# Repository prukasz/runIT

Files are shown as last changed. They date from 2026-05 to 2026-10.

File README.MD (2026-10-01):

# runIT

> **`YOU can run IT`**

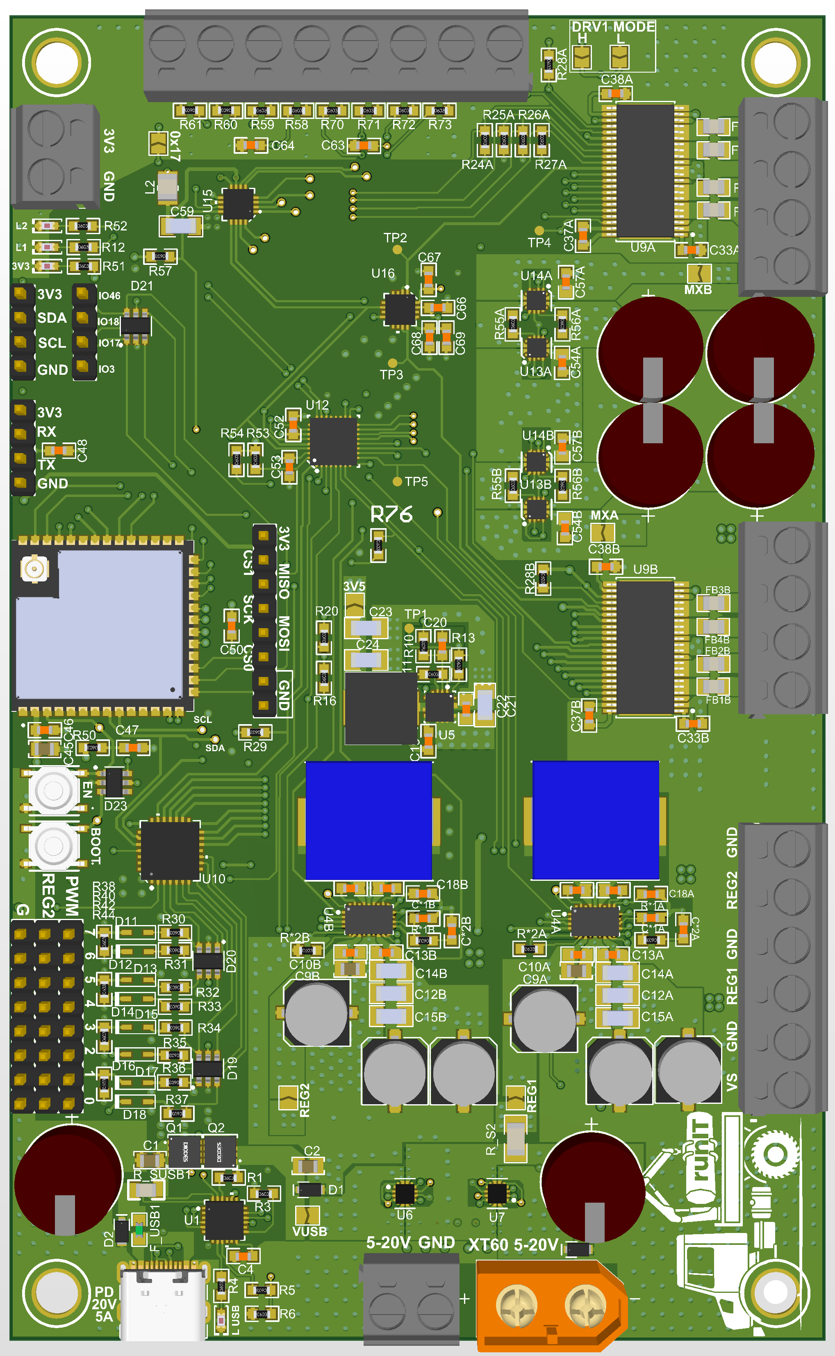
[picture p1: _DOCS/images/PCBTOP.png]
Płytka runIT, widok z góry PCBTOP


---

## Czym jest runIT?

**runIT** to kontroler łączący pogranicze **IoT**, modelarstwa **RC** oraz **automatyki**.

Pozwoli Ci on na podłączenie standardowych elementów RC (takich jak serwa, ESC, różnego rodzaju aktuatory) oraz łatwą integrację popularnych czujników i pasków LED. Dzięki aplikacji stworzysz interfejs sterowania, a za pomocą prostego języka graficznego uczynisz swój projekt "SMART" i podłączysz go do sieci.

## Co oferuje sterownik runIT

- PowerIO 20V
- Dwie regulowane przetwornice DC-DC
- Elastyczne zasilanie, w tym USB-C PD
- PWM expander
- WiFi + BLE
- Zabezpieczenia

Całość na popularnym mikrokontrolerze ESP32-S3.

### PowerIO

- 4 konfigurowalne mostki H (8 wyjść) - nawet 20V 5A
- 8 wejść analogowo-cyfrowych gotowych do bezpośredniej pracy z napięciem do 20V
- System wyboru źródeł zasilania dla mostków H - zasil elementy wymagające różnych napięć bezpośrednio z płytki
- Zasilanie mostków H z przetwornic DC-DC lub bezpośrednio z zasilacza
- Pomiar poboru prądu i tryb Constant Current

### Regulowane przetwornice DC-DC

- Swobodna regulacja w zakresie 4.5V - 20V
- Zabezpieczenia przeciwzwarciowe i przeciążeniowe
- Limit poboru prądu
- Wyjścia bezpośrednio z przetwornicy - zasilacz regulowany

### USB-C PD i wejście uniwersalne zasilania

- Wsparcie USB-C PD 3.0 20V-5A
- Wejście na akumulator lub zasilacz 5V - 20V wraz z pomiarem poboru prądu i napięcia
- Możliwość koegzystencji obu wejść zasilania

### PWM expander

- 8 kanałów dedykowanych wraz z wyjściami 3-pinowymi
- Współpraca z Servo i ESC bez zajmowania innych kanałów

### WiFi + BLE

- Połączenie WiFi i BLE lub oba na raz

### Zabezpieczenia

- E-bezpieczniki
- Zabezpieczenie przeciwko odwrotnej polaryzacji
- Zabezpieczenia ESD
- Izolowane zasilanie 3.3V
- Regulowany limit prądu zasilania
- Pomiar napięcia i poboru prądu - alerty

### ESP32-S3

- Wyprowadzone GPIO, w tym SPI i I2C
- Brak ograniczenia jedynie do wbudowanych peryferiów - podłącz popularne czujniki
- Ekosystem ESP-IDF - łatwa modyfikacja do swoich potrzeb

## Co oferuje oprogramowanie

- Prosty język blokowy z wbudowanym wsparciem "RC"
- Tryb smart - pilot RC
- Wsparcie dla popularnych elementów modelarskich
- Prosta konfiguracja podpiętych elementów oraz WiFi i BLE
- Ułatwione wykrywanie błędów
- Łatwy dostęp do danych telemetrycznych
- Zabezpieczenia działające w tle

### Język blokowy

- Drag 'n drop
- Automatyzacja prostych rozwiązań
- Wyślij zebrane dane przez BLE lub WiFi
- Dedykowane bloki sterujące dla elementów modelarskich
- Podgląd zmiennych na żywo
- Edycja kodu na żywo i OTA
- Ułatwiona konfiguracja podpiętych elementów i wybranego zasilania - ustaw napięcie, a resztą zajmie się oprogramowanie

### Tryb RC

- Połącz kod z pilotem na urządzeniu
- Wykonuj skomplikowane sekwencje niemożliwe w zwykłej aparaturze RC

### Potrzebujesz bardziej skomplikowanego oprogramowania?

- Zaimplementuj je równolegle w C i utwórz nowy blok
- Uruchom go równolegle z kodem blokowym
- Wykorzystaj sprzęt oraz sterowniki i napisz własny kod

---

## Stan projektu

**Płytka jest już wyprodukowana i uruchamiana.** Firmware i aplikacja powstają równolegle.

### Działa (sprawdzone na płytce)

- Uniwersalny system wymiany danych z aplikacją - przez BLE i UART
- Sterowniki: GPIO ESP, ekspander TCA6424A, ADC ADS7128, PWM PCA9685, USB-C PD AP33772S i kolejne układy zasilania
- Komendy, odpowiedzi, błędy i logi dekodowane w aplikacji
- Zdarzenia na urządzeniach i akcje uruchamiane zdarzeniami
- Maszyna wirtualna (VM) z 15 typami bloków, m.in. wyrażenia, warunki, pętle, timery, zatrzask, detektor zbocza, wyjścia IO
- Zapis programu w pamięci płytki i jego wczytanie po restarcie
- Aplikacja (przeglądarka, Web Bluetooth): widok płytki i urządzeń, edytor bloków z płótnem (canvas), kompilator programu, tryb debugowania z podglądem zmiennych na żywo

### W trakcie

- Wysyłanie programu z edytora blokowego na płytkę w pełnym przepływie z poziomu aplikacji
- Wybór źródła zasilania mostków H (z blokadą przed zwarciem źródeł)
- Zasilanie: potwierdzenie kolejności kanałów INA3221, wskaźniki źródła, estymaty
- Testy VM na sprzęcie dla bloków Latch, Periodic, Action i On Event

### Planowane

- Tryb RC - pilot w aplikacji połączony z kodem blokowym
- Telemetria i rejestrator danych
- Strona zasilania i subskrypcji zdarzeń w aplikacji
- WiFi (w tym MQTT) jako kolejny kanał danych
- Aplikacja mobilna (Android)

## Struktura repozytorium

| Folder | Zawartość |
|---|---|
| `_SOFTWARE` | Firmware ESP32-S3 (ESP-IDF), deskryptory danych i aplikacja webowa |
| `_HARDWARE` | Projekt płytki: schematy i PCB (Altium) |
| `_DOCS` | Obrazy i dokumentacja do README |

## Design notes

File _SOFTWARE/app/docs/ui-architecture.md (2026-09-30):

# UI architecture

## Screen frame

`src/App.tsx` coordinates the active view and workspaces. It supplies content to `src/layout/WorkspaceLayout.tsx`, which owns the stable three-column structure:

| Region | Purpose | Typical content |
| --- | --- | --- |
| Explorer | Tree, palette, and lists | Variables, blocks, devices, settings categories |
| Main screen | Canvas or editor | Block canvas, object editor, device editor, settings editor |
| Details | Selection details and actions | Block settings, object information, device commands, run and connection panels |

The main screen receives a toolbar slot from `App.tsx`, so actions can change with the active view without changing the frame. The terminal is below the main screen.

The explorer and details panels share `side-panel`, `side-panel-header`, and `side-panel-collapsed-icons` styles. The three panel resize handles share `panel-resize-handle`; their direction and placement stay in the feature classes.

## Shared controls

| Component | Use |
| --- | --- |
| `components/FormField/TextField` | Native text and number inputs with shared border, focus, disabled, and invalid states. Checkbox, file, and other native controls retain their native appearance. |
| `components/FormField/SelectField` | Native dropdowns with the same field surface and focus behavior. Keep native select semantics for finite choices. |
| `components/EditableField` | A text field with an edit or protected icon. Supports editable, read-only, and disabled values. |
| `components/ListableField` | A dropdown with option data and a chevron or locked icon; built on `SelectField`. |
| `components/PaletteSearch` | Search input, icon, clear action, and Escape behavior for explorer palettes. Views supply their own filtering rules. |
| `components/PaletteSectionHeader` | Collapsible palette heading with chevron, label, filtered count, and optional Add action. Views own expanded state and filtering. |
| `components/InlineRename` | One commit or cancel path for canvas names, block names, and aliases; callers decide how to validate the final text. |
| `components/Badge` | Passive chip for system markers, IDs, counts, BLE flags and directions, detail labels, and type codes. Set a semantic `tone`; use `size="compact"` for dense flags, `size="detail"` in inspectors, `caps` for uppercase status text, and `push` for edge alignment. `filled` is used for prominent accent labels. |
| `components/Button` | `Button` (`variant`: default, primary, danger, dashed; `size`: md 32px, sm 28px, icon, icon-sm; `block` fills the row), `buttonClass()` for a link styled as a button, and `ToggleChip` (pill with `selected`). Features add no button colors, borders, or icon sizes of their own; toolbar and tree icon buttons keep the shell's plain `.shell button` style. |
| `components/Card` | `Card` (title, optional amber `icon`, `subhead`) is the panel surface for a group of settings; `CardStack` stacks the cards of one editor page. |
| `components/FormField/FormRow` | `FormRow` (label above one control, optional `htmlFor` / `note` through `FieldLabel`, `hint` under the control) and `FormGrid` (two columns, one when narrow). |
| `components/PanelHeader` | Title row at the top of a details panel: leading `icon`, `title`, then badges or actions as children. |
| `components/TypeBadge` | Exact VM or BLE type codes and the broader value-kind icon used on objects and block pins. |
| `components/OptionMenu` | Rich option lists with a shared option row, selection state, arrow navigation, and Escape. Canvas wiring and accessor suggestions use it. |
| `components/TreeSlab` | Shared leading badge, label, trailing badges, and optional action row for variables, devices, connectors, and the block palette. |

`TreeSlab.css` owns row selection, folder, search match, link target, drag, and drop states. A feature should add only its own row content or spacing rules.
Use `Badge` for static labels. Buttons and selectable chips keep their own interaction styles and semantics.
Flat palettes can give the row a `listitem` role and disable activation when their item is unavailable. The row's main button supplies Enter and Space activation; drag handlers remain on the row container.

Use a native select for ordinary finite choices. Use `OptionMenu` when a row needs badges, descriptive text, live filtering, or a drop target. Keep the options and their domain rules in the feature; the shared component owns the common interaction and surface.

Use `form-field-panel` on `TextField` or `SelectField` for fields on a panel surface. A compact field can set `--field-height`, `--field-padding`, and `--field-font-size` on its container. The shared control keeps the border, focus, and disabled states.

`EditableField` and `ListableField` share the `adorned-field-wrap` and `field-adornment-*` styles from `FormField.css`. Their own stylesheets contain only control-specific sizing. Native fields supplied through `TextField` and `SelectField` should keep their common border, colors, and focus state in `FormField.css`; feature CSS should only override the needed dimensions or layout.

## Feature boundaries

`src/domain/` contains project data, catalogs, wiring, compilation, and other rules independent of React. `src/devices/` and the workspace modules contain their feature views and state hooks.

The canvas feature is grouped by responsibility:

| Directory | Contents |
| --- | --- |
| `canvas/blocks/` | Block rendering, details, formula editing, pin helpers, and block-specific rules. Accessor parsing lives in `pinAccessors.ts`; `PinHelpers.tsx` uses it. |
| `canvas/surface/` | Pan and zoom interaction, wires, free chips, and branch or loop regions. |
| `canvas/workspace/` | Canvas editor composition, tabs, block palette, and workspace state. |
| `canvas/index.ts` | Public imports for the rest of the app. |

`canvas/Canvas.css` remains the feature stylesheet and is imported by the feature views.

## File view

`ProjectFile.tsx` is the File view (first icon in the left rail): the left panel holds New, Open, Save (project file), Import and Export (code file, `runit-code`) and Recover from board; the main screen shows what the project holds and the code it builds. The Run view keeps only what changes a board: Store, Load, Erase. `useProjectCode` builds the code once for both.

## Names shown to users

Block enable pins keep their PLC names in code, data files and paths (`EN`, `ENO`, `enables`, `<id>:eno`), but the screen says what they do: **EN** is **Run when** (the block runs only while it is true), **ENO** is **When done** (true after the block ran), and a FOR's ENO is **Loop body**. Use these in labels, titles, hints and messages.

## Color palette

`src/styles/theme.css` is the source of dark and light theme colors. The shell owns surface tokens such as `--background`, `--panel`, `--divider`, `--active`, `--muted`, and the blue selection token `--accent`. Use `--color-*` for status and accent hues, `--type-*` for badges, `--category-*` for block categories, `--group-tint-*` for canvas contours, and `--syntax-*` for expression text. Mix a token with `transparent` for translucent backgrounds and glows so both themes use the same hue. Keep literal colors only for fixed contrast marks or artwork.

`src/hooks/useStorage.ts` owns browser storage: `readStored` / `usePersistEffect` for workspace data, `usePersistedChoice` / `usePersistedFlag` for remembered preferences (tab, mode, theme, snap). Every read and write is guarded, so a view never repeats the try/catch. `src/hooks/useUndoHistory.ts` owns the common undo transitions and 50-entry limit. Object edits can group rapid changes with a key; project loads in canvas, devices, and objects are undoable, while loading a BLE profile starts a fresh history. Each workspace keeps its own storage, validation, and selection behavior.

When adding a screen, provide its explorer, main content, details, and toolbar actions through `App.tsx`. Reuse the shared controls before adding feature-specific field or dropdown styling. Feature CSS should describe layout and meaning, such as the importance level color; control focus and disabled behavior belong to the shared component.

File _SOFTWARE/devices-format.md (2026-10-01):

PORTS:

POWER:
SUPPLY_OUT {MIN mV/mA,MAX mV /mA, REGULATED, POWER_MAX}
SUPPLY_IN {MIN,MAX}
GND {}
MEASURE_IN{MIN, MAX}
MEASURE_OUT

IO: + overall types (pullup and so on)
BINARY
PWM 
ADC
DAC
PROTOCOL(i2c){MEMEBER(SCL)} 

do tego defaul modes itd

descripotion of PORT:
PORT + name + svg id + real-device-id if possible to configure

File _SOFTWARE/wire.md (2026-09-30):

First read concept if unsure ask. 
I dont know how to make EN and ENO seamless for user - so he uses if only wants
help me with thise one settled we move to implementation 

First global variable accessor:
- let it be a short rectangle with name of accessed
- if to long - truncated to last important path like ...temperature 
- when clicked then automatically right screen pops out to edit if requires manual. 
- if drag n drop is enough - it should be enough to drag from folders and varaibles and put on block 
- when hovered over block during wiring - there appears zoom over block with pin to chose or EN 
- IN can be selectable both by dropping object on enlarged pin or by clicking on pin in enlarged view

- when enlarged view displays few pins - only compatible type is allowed (number and bool are casted - so allowed ) but ptr and string is not capable 

- you can drop empty accessor from top toolbar - that way every pin is allowed to drop on but still end result must be compatible

- if possible accessor should then snap to block - so no wire but still if required can be moved out with an wire

Then ENO and EN:

- ENO is Green stripe 
- EN is Red stripe

- When output of block is connected to input of any - then ENO is automatically - linked 

Then canvas marking:

- Every block in for loop should be included as grouped in smoke like area - contour - those then can overlap with eachother. each of group are shold posess slight coloru tint
- same thing for IF block and SWITCH. this will visually help understand code

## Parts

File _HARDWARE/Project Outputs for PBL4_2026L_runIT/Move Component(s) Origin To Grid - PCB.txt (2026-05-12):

Move Component Origin to Grid
Filename     : C:\Users\krolp\Documents\runIT\_HARDWARE\PCB.PcbDoc
Date         : 02.04.2026
Time         : 00:08:12
Time Elapsed : 00:00:00

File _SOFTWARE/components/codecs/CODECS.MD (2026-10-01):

# CODECS — Packet Decoder Tables

`codecs` is a **header-only** component holding the packet tables that [[SYS_INTERFACE.MD]] routes to. It has no source files and produces no library — `idf_component_register()` only exports `decoders/` (inbound packet tables, one header per class byte).

Every class is registered with `sys_interface` by runit's `runit_register_decoders` boot step (`components/runit/runit.c`), before `sys_interface_init()` starts the RX receiver. `sys_interface` itself doesn't depend on `codecs`.

The error-chain encoder that used to live in `encoders/` is private to `sys_errors` now (`components/sys_errors/enc_sys_errors.h`); its wire format is in [[SYS_ERRORS.MD]] "Logging and telemetry".

The split of responsibility: `sys_interface` owns the **class byte** (`0xXX`) and the transport plumbing; a codec header owns its **packet bytes** (`0xYY`), payload layouts, and the mapping to `sys_*` API calls.

---

## `decoders/dec_sys_contracts.h` — class `0x01`

Maps packet bytes onto the system contract APIs (`sys_device`, `sys_io`, `sys_power`). Everything is `static inline` in one header, so adding a packet is a single-file change with no build-system edits.

Each entry is three pieces:

```c
#define HEADER_packet_sys_io_toggle_t 0x24          // 1. packet byte
typedef struct __packed {                            // 2. payload layout
  uint8_t device_id;
  uint8_t pin;
} packet_sys_io_toggle_t;

static inline err_h decoder_packet_sys_io_toggle_t(packet_sys_io_toggle_t* packet) {
  ESP_LOGI(DEC_SYS_CONTRACTS_TAG, "toggling io (dev %u, pin %u)", packet->device_id, packet->pin);
  return sys_io_toggle(SYS_IO_REF(packet->device_id, packet->pin));
}
```

...plus a row in the central `X`-macro list:

```c
#define SYS_CONTRACTS_PACKET_LIST(X) \
  ...                                 \
  X(HEADER_packet_sys_io_toggle_t, packet_sys_io_toggle_t, decoder_packet_sys_io_toggle_t)
```

`SYS_CONTRACTS_PACKET_LIST` expands through `SYS_CONTRACTS_DECODE_CASE` into the `switch` inside `dec_sys_contracts_decode()`, which runit registers for class `0x01`. Each case declares the payload struct on the stack, fills it via `convert_to_packet()` (length-checked), and calls the decoder.

Every decoder logs what it is about to do at `ESP_LOGI` under the tag `dec_sys_contracts`. A getter returns its result in the command's response: it declares `packet_<name>_response_t` (packed, scalars or fixed scalar arrays, same field annotations) next to its request struct and calls `sys_interface_respond(&rsp, sizeof(rsp))`. Every command is answered (`[0x05][seq][class][packet][status][data]`, see [[SYS_INTERFACE.MD]] "Responses"). The contracts generator publishes the response layout.

### Packet Byte Ranges

| Range | Domain | API |
| :--- | :--- | :--- |
| `0x10`–`0x15`, `0x1A`–`0x1C` | Device lifecycle | `sys_device_user_uninstall` (onboard devices are refused), `reset/suspend/resume` (+ `_all` variants; `0x1C` → `sys_device_user_uninstall_all`, which skips onboard devices) |
| `0x1A` | Device error handling | `sys_device_set_error_handling` — `device_id, importance, actions[5]`; see [[SYS_DEVICE.MD]]'s "Per-Instance Error Handling" |
| `0x1B`–`0x1F` | *(free)* | |
| `0x20`–`0x2F` | IO | `sys_io_reset/set_mode/set_level/get_level/toggle/get_voltage/set_voltage/set_pwm_frequency/set_pwm_duty`, `0x29`: `sys_io_configure_intr` (mode, debounce, ADC window; arms the pin only, events are linked with class `0x09`) |
| `0x31`–`0x3E` | Power | `sys_power_vreg_set_enable/voltage/current` (budgeted, current 0 = automatic), `sys_power_monitor_get_voltage/current`, `sys_power_usb_pd_set/list/get_limits`, `0x39`: `sys_power_monitor_set_alert` (current alert threshold), `0x3C`: `sys_power_get_status` (response), `0x3D`: `sys_power_set_response`. `0x30`, `0x3A`, `0x3B` and `0x3E` are free. Persisted PSU / battery settings are settings class `0x08` (`dec_settings_power.h`). |
| `0x51`–`0x53` | H-bridge | `sys_hbridge_set_drive/brake/coast`. `0x50`, `0x54`–`0x56` are free: set_mode, set_current_limit and clear_fault were chip specifics and are operations of the DRV8962 now (`0x80`–`0x82`, [[SYS_DEVICE.MD]] Packet Router). Faults are events, class `0x09`. |
| `0x00`, `0x80`–`0xFF` | Device router | create a device by type id; operations of a device ([[SYS_DEVICE.MD]], Packet Router) |

Unmapped packet bytes raise `ERR_INTERFACE_UNKNOWN_PACKET` (owner `OWNER_DEC_SYS_CONTRACTS`) and log a warning.

---

## Device creation — class `0x01`, header `0x00`

Devices have no install packets (the old `0x40`–`0x47` decoders are gone). A device is created by the packet router: `[0x00][type_id][d_<chip>_cfg_t]`, where the cfg is the device's own `__packed` wire struct, device_id first. `sys_device_route()` finds the class by `type_id` and `sys_device_create()` checks the size and the pin order ([[SYS_DEVICE.MD]], Packet Router). The cfg struct and its annotations live in the device's own header (`components/devices/device_<chip>/include/device_<chip>.h`), which the device generator reads.

A pin on another device is a `sys_io_pin_ref_t` (`device_id, pin, mode`, three bytes). **An unused pin must be encoded as `pin == SYS_GPIO_NONE`** (`0xFF`); sending all-zero fields means "device 0, pin 0", a real pin. `i2c_bus` is a single byte (`0` = internal, any other value = external bus). Example: a PCA9685 as device 5 on the internal bus at I2C address `0x40`, no OE pin: `01 00 41 05 00 40 00 FF 00`.

---

## `decoders/dec_sys_actions.h` — class `0x03`

Control-packet table for [[SYS_ACTIONS.MD]]'s record/stop/remove wire protocol. Same shape as `dec_sys_contracts.h` (a `SYS_ACTIONS_PACKET_LIST` X-macro expanded into a switch), just with `sys_actions.h` in place of `sys_io.h`/`sys_device.h`/`sys_power.h` as the thing being wrapped.

| Packet | Byte | Payload | Calls |
| :--- | :--- | :--- | :--- |
| Static Invoke | `0x00` | `uint8_t id` | `sys_actions_invoke(SYS_ACTION_SCOPE_STATIC, id)` |
| Dynamic Invoke | `0x01` | `uint8_t id` | `sys_actions_invoke(SYS_ACTION_SCOPE_DYNAMIC, id)` |
| Record Start | `0x02` | `uint8_t id` | `sys_action_record_start(id)` |
| Record Stop | `0x03` | *(empty)* | `sys_action_record_stop()` (persists to NVS) |
| Remove | `0x04` | `uint8_t id` | `sys_action_remove(id)` |
| Remove All | `0x05` | *(empty)* | `sys_action_remove_all()` |

`CONFIG_RX_PACKET_CLASS_SYS_ACTIONS` (`0x03`) and every other class/packet wire-identity byte are Kconfig options under `components/utils/Kconfig`'s "System-Wide Identity Assignments" menu, not `#define`s in any one file — see that menu's "RX/TX Packet Classes" and "RX/TX Packet Headers" submenus for the full byte-0/byte-1 naming scheme. `dec_sys_actions.h` includes `sys_actions.h` for the rest of that component's own API, not for this constant.

Registered by runit like every other class. There is no separate "bind action to state" class anymore — the `sys_states` component that used to own it was folded into `sys_actions` (a hardcoded behavior is now just a bound static function on an action id, see [[SYS_ACTIONS.MD]]); class `0x04` was freed by that change and has since been taken by the VM loader below.

---

## `decoders/dec_vm_loader.h` — class `0x04`

Records are the packed structs of `VM/core/loader/vm_wire.h`, published to `data-structures/vm/vm-program.generated.json`.

Program-upload table for [[VM.MD]]. **Structurally different from the tables above**: these packets are not fixed-size structs, so there is no `X`-macro packet list and no `convert_to_packet()` copy. `0x42`/`0x43` carry a repeating record list whose entries vary in length (inline name bytes, inline payload bytes), so they are walked with an explicit cursor.

| Packet | Byte | Payload | Calls |
| :--- | :--- | :--- | :--- |
| Reset | `0x40` | — | `vm_loader_reset()` |
| Open | `0x41` | `u16 obj_cnt`, `u16 acc_cnt`, `u16 blk_cnt`, `u32 total_size` | `vm_loader_open()` |
| Add objects | `0x42` | `u8 n`, `n ×` `{u16 id, vm_obj_head_t head, char name[head.d.name_size]}` | `vm_loader_add_obj()` per record |
| Set data | `0x43` | `u8 n`, `n ×` `{u16 id, u16 start_idx, u16 byte_len, u8 data[byte_len]}` | `vm_loader_set_data()` per record |
| Add accessors | `0x44` | `u8 n`, `n ×` `{u16 acc_id, u16 root_obj_id, u8 idx_count, u8 idx_len, u8 idx_data[idx_len]}` | `vm_loader_add_accessor()` per record |
| Add block | `0x45` | one block: header, `in_cnt ×` accessor id, `q_cnt ×` object id, `en_cnt ×` accessor id, `custom_len ×` private state | `vm_loader_add_block()` |

`idx_data` holds `idx_count` records of `{u8 kind, payload}` — `LITERAL` a `u32` position, `REF` a `u16` accessor id, `NAME` a `u8` length then that many unterminated bytes. A `REF` target must already exist, which makes reference cycles unconstructable rather than merely depth-capped at resolve time.

`0x45` carries exactly **one** block, unlike everything else here: a block record varies in length four separate ways, so batching would need a length prefix per record and a cursor that can desynchronise. A block names accessors and objects that must already be bound. **Block order is execution order** — the client topologically sorts and uploads in that order.

All multi-byte fields little-endian. Every length is checked against the bytes actually present before use (`DEC_VM_NEED`), raising `ERR_VM_LOAD_SHORT_RECORD` rather than reading past the frame — the cursor walk has no struct-size check to lean on, so this is the only thing standing between a truncated frame and an overread.

`DEC_VM_NEED`'s parameters are named `in_pkt`/`in_off`/`in_len`/`in_need` so plain token substitution cannot collide with the `.packet`/`.need`/`.got` payload designators inside it — the same hazard `SE_CHECK_IN_RANGE` documents in [[SYS_ERRORS.MD]]. Naming them `packet`/`need` expands `.packet = (packet)` into `.0x41 = (0x41)`.

Wire-format rationale (`start_idx` unconditional, `payload_size` in bytes rather than an element count, explicit flags byte rather than the raw header bitfield, child **ids** rather than pointers for `VM_OBJ_PTR`) is documented in [[VM.MD]].

Registered by runit like every other class. The VM can't register it itself: `codecs` `REQUIRES VM` so the decoder can see `vm_loader.h`, which would make a `VM → codecs` dependency circular.

---

## `decoders/dec_settings_project.h` — class `0x0A`

Stored code ([[SYS_PROJECT.MD]]): begin / write / commit / abort / erase / options / info / read / load. Settings-style table (`//@settings project`, published to `settings.generated.json`, the `info` response layout too). `write` carries a trailing `uint8_t data[]` (the settings generator publishes it as `flexible_array` without an encoding: opaque bytes); `read` answers with the raw bytes. The header also holds the commit filter (`dec_settings_project_frame_allowed`: no class `0x0A`, no action recording, no VM exec) and `dec_settings_project_is_vm_frame` for the boot replay, which runit wires in `runit_project_boot`.

---

## `decoders/dec_sys_events.h` — class `0x09`

Links events to the program and to actions ([[SYS_EVENT.MD]]). Exposed as the `events` contract catalog.

| Packet | Payload | Response |
|---|---|---|
| `0x01` subscribe | `domain, device_id, channel, event` (255 = any), `route_mask` (bit 0 = program), `static_action_id`, `dynamic_action_id` | `subscription_id` |
| `0x02` unsubscribe | `subscription_id` (255 = every subscription made by packets) | — |

Packet subscriptions are user-owned: the unsubscribe packet can't remove the system's own (device IRQ chaining, power manager). Tagged `OWNER_DEC_SYS_EVENTS` (`0xA618`).

---

## Adding a New Class

Copy the shape of `dec_sys_contracts.h`:

1. Create `decoders/dec_<name>.h` and add a `config RX_PACKET_CLASS_<NAME>` (`hex`, `default 0xXX`) to `components/utils/Kconfig`'s "RX Packet Classes" submenu, under "System-Wide Identity Assignments" — do not `#define` the class byte in the decoder file itself.
2. Set `#undef OWNER` / `#define OWNER OWNER_<NAME>` near the top so `SE_*` macros tag errors correctly, and add that owner to the module's `sys_error_*.h` owner map.
3. Expose one `static inline err_h dec_<name>_decode(const uint8_t* data, size_t len)` — `data[0]` is the packet byte.
4. Register it in `runit_register_decoders()` (`components/runit/runit.c`): `sys_interface_register_decoder(CONFIG_RX_PACKET_CLASS_<NAME>, dec_<name>_decode, "<name>")`.

Per-packet header bytes (byte-1, `data[0]` inside the decoder) stay local `#define HEADER_packet_<struct>_t 0xYY` in the decoder file, as today — only the outer class byte (byte-0) moved to Kconfig, since it's the one value that must stay globally unique across every registered decoder.

Note that a decoder header defines `OWNER` for the rest of the translation unit; any `.c` including it must re-`#define OWNER` afterwards. This is why the registrations live in their own file, `runit.c`.

**Splitting a class across files.** If one class's packet table grows too large for one header, split it into a second header: give the split-out file its own `OWNER`/log tag and its own `SOME_NAME_PACKET_LIST(X)`, then have the original file `#include` it and fold that list into its own via `SOME_NAME_PACKET_LIST(X)` as one line inside its own `X`-macro definition (same technique `sys_error_codes.h` uses to combine multiple modules' `SYS_ERROR_*_MAP(X)`s into one `SYS_ERROR_MAP(X)`). The class byte, dispatcher function, and registration call stay in the original file — only packet declarations move.

### VM execution control

`04 48 <command>` is the single execution-control packet; the command is one
byte and no additional payload is accepted. Commands `00` through `08` select
scan mode, execute once, select block mode, execute next, reset to scan start,
select normal mode, pause, resume, and reset/unload respectively. See
`components/VM/VM.MD` for stepping and reset semantics and
`vm_exec_command_e` for the C constants.

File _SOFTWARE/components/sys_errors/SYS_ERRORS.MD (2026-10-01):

# System errors

Update this document when changing the error core, dispatcher, or tag maps.

## Pipeline and ownership

Errors are typed nodes linked through `next_cause`. `NULL` means success.
`SE_ERR_NEW` creates an owned node; `SE_WRAP_ERR` transfers ownership of its cause
into the new chain. Explicit-owner variants use the same allocator/constructors.
Do not share a cause between two owned chains.

```text
create -> wrap while returning -> SE_REPORT / SE_push_to_handler
       -> validate -> outermost node through causes -> diagnostics -> release
```

`SE_push_to_handler` **consumes** its argument, including when reporting is
suspended. Do not inspect, return, or release that handle afterwards.

- **Responses run synchronously** in the reporting task (device policy, domain hooks,
  system fault), so a response happens before anything else can build on the
  unhandled error.
- **Logging and telemetry run later** in the error log task: `SE_log(chain)` queues
  the chain (consumes it), and that task logs, encodes, sends and releases it. The
  ~1.5 KB of format/encode buffers live on that task's stack, not on the stack of
  every task that raises errors.
- **Queue full:** a chain that finds the queue full (`CONFIG_SYS_ERRORS_LOG_QUEUE_LEN`,
  default 4) is released and counted, and the count is logged.
- **Waiting chains keep their pool nodes,** so keep the queue short.

`SE_send`, the encoder, logging functions, and policy hooks **borrow** their input.
They do not retain it. Their non-NULL return is a separate owned failure.
Use `SE_release(error)` after inspecting/discarding an error yourself.
`SE_IS_OK` / `SE_IS_ERR` only compare; they do not release an error.

```c
err_h error = operation();
if (error) {
  SE_log(error);             // diagnostics only (queued, consumed); or return error to the caller
}
// At an origin with no further use of the error:
SE_REPORT(operation());
```

## Storage and validation

The shared pool is 1,024 bytes: 32 blocks of 32 bytes, reserved with a 32-bit atomic
bitmap. A node occupies consecutive blocks. A 32-byte start-length table validates
node boundaries and complete tag-sized payloads. Tracking costs 36 bytes. There is
no heap allocation and live nodes are never overwritten. Payloads and nodes remain
8-byte aligned. Maximum concurrent capacity depends on payload sizes (up to 32
small nodes); synchronous handling does not eliminate overlapping producer tasks.

`SE_alloc_bytes` validates tag and exact payload size and returns NULL on exhaustion.
Prefer the constructors: a failed new error returns an immutable
`ERR_BASE_POOL_EXHAUSTED` node. It is LOW severity on purpose: a burst of errors
must not trigger the safe state. Pool size: `SYS_ERRORS_BUF_SIZE / SYS_ERRORS_BLOCK_SIZE`
must be at most 32 blocks (one `uint32_t` bitmap, checked at compile time); a failed wrap preserves its existing cause, omitting the new context. Never
mutate the exhaustion node. Long-lived errors consume pool capacity until released.
The pool can exhaust without corrupting another chain; it does not guarantee that
all context can be retained during an error storm.

`SE_collect_chain` returns at most `SE_MAX_CHAIN_DEPTH` (16) unique validated nodes,
outermost first, plus a completeness flag. Handler, logger, encoder and root lookup
share this traversal. Cycles, invalid pointers and longer chains terminate safely.
Malformed/incomplete chains are diagnostic-only. `SE_release` frees the complete
pool-backed chain (also beyond the traversal limit) with bounded cycle detection.
Raw pointers are not generation handles: using a handle after consumption/release
remains invalid, even if its address is later allocated again.

## Dispatch policy

- Device attribution uses the tag payload, independently of the reporting owner.
  Device tags, IO pin tags and power-budget tags identify device instances; each module
  lists its own in `SYS_ERROR_<MODULE>_DEVICE_TAGS(X)` next to its tag definitions, and
  `SYS_ERROR_DEVICE_TAGS(X)` (`sys_error_codes.h`) gathers them for the handler. A listed
  tag without a `dev_id` member does not compile.
  Contract boundaries wrap failures with the affected device ID.
- Visit outermost node to root cause. For a repeated device, use the highest local
  severity among its mentions before the first ignored-device boundary. Run that
  device's policy once, at its first occurrence; pass the node supplying that level.
  The leaf does not silently replace another node's severity.
- A dependency wrapper (`ERR_DEV_DEP_FAILED`, `ERR_DEP_FAILED`) has no severity of its
  own for a device: it takes the severity of the first node below it that is not a
  wrapper. The dispatchers wrap every failure of a device call in `ERR_DEV_DEP_FAILED`
  (HIGH), so without this rule a rejected argument (`ERR_INVALID_VAL_*`, LOW) would
  count as a HIGH fault and run the device's action. A chain made only of wrappers
  keeps the node's own severity. Non-device nodes (domain hooks, the system hook)
  are classified by their own tag as before.
- Importance NONE stops all handling of that device and all deeper causes,
  critical nodes included (the user's opt-out for a device under test). Earlier
  responses remain in effect; the full chain still goes to diagnostics.
- From LOW (a device's start value) up, importance filters which noncritical
  severities reach the device policy: MEDIUM admits HIGH, HIGH admits MEDIUM and
  HIGH, CRITICAL admits all. Critical always goes through. Tag severities stay
  unchanged.
- Domain hooks receive `(node, full_chain)` for each visited node in that domain.
  Hooks are registered at boot (`SE_register_domain_hook(domain, fn)`, a table of
  `CONFIG_SYS_ERRORS_MAX_DOMAIN_HOOKS`); a domain without one is skipped. The device
  router (`SE_register_device_router`) and the system hook (`SE_register_system_hook`)
  are registered the same way. runit does all of it in `runit_error_wiring_init()`,
  the first boot step after `SE_init()`.
- Unattributed critical errors (where no device in the chain was attributed,
  `handled == 0`) use the registered system hook, never a lookup of device zero.
  The application latches the triggering node and performs global stop/suspend
  once per latch episode. Enabled devices still run their individual actions
  after the global latch has been set. The dispatcher deduplicates devices
  per incident, not across separate incidents.
- Response failures are diagnostics-only and released after sending. A per-task
  handler guard prevents callbacks/actions re-entering policy while handling an
  incident. Hooks must return new owned failures, never the borrowed input chain.

`SE_suspend` / `SE_resume` are nested and task-local. Suppression in one task does
not drop unrelated errors from another task. The synchronous dispatch/logging API
is for task context; it can invoke actions, transport callbacks and VM barriers.

## Logging and telemetry

`SE_set_logging(level, mirror_serial, trace_errors)` controls text logging and the
ESP log interceptor. `sys_errors` knows no transport: output goes to a sink the
application binds at boot with `SE_register_sink(&(sys_error_sink_t){send_log,
send_packet, packet_max_len})`. runit (`runit_board_error_sink_init`) sends text
lines to the logs connector and binary error packets to the errors connector.
`packet_max_len` is a function asked before every packet, because the transport
limit changes at runtime (runit returns `sys_data_connector_max_payload()` of the
errors connector, which follows the BLE MTU); the encoder packs as many chain
nodes as fit. Unbound outputs are dropped; serial mirroring
still works. Binary errors go out independently of text tracing. The encoder is
private to this component (`enc_sys_errors.h`). The disconnected `sys_error_config` API was removed.
`SE_send` does not acknowledge delivery: the sink's send functions are void, and
runit releases a failed connector send there (reporting it would recurse into the sink).
Its returned error describes encoding failure. Log recursion guards are task-local.

The binary format (no version field; formats aren't versioned before release):

```text
u8 node_count | u8 depth | u32 schema_id LE
repeated: u8 payload_length | u16 tag LE | u16 owner LE | payload bytes
```

- **Tag IDs are explicit and stable:** `X(tag, id, level, struct)`. The high byte is
  the module's owner domain (`0xA3xx` IO, `0xA1xx` devices, and so on), and `0x00xx` holds
  the shared base tags; 0 means "no tag".
- **Adding a tag doesn't renumber the others,** so a client's tag table stays valid
  for existing tags. Duplicate IDs fail the build (duplicate `case` in
  `SE_get_tag_name`).

`depth > node_count` indicates packet-capacity truncation. Depth 255 means corrupt
or over-depth input (the exact length is unknown). The schema ID is FNV-1a over
the tags' NUL-terminated names, IDs and payload sizes in map order. It detects
added tags and payload-size changes; with stable IDs a client can still decode
the tags it knows when the schema differs. A same-size payload-layout
change isn't detected by the schema ID; the client's tables must be regenerated with it. Payloads retain native C alignment
and padding; scalar record headers are explicitly little endian.

Formatted logs still supply human-readable descriptions. Clients with a
matching schema may decode typed payloads.

**Client tables:** `data-structures/errors/errors.generated.json`
(`generate-errors.py`, see `data-structures/AGENTS.md`) publishes every tag,
owner, severity, payload layout (native offsets), `LOG_BODY` format and the
schema ID computed the same way as `SE_schema_id()`. The app decodes error
packets from it. Keep `LOG_BODY_*` to one `snprintf` over payload fields
(helpers of the form `switch` → `return "text"` or `(r) == N ? "text" : …`
are published as value tables); a body with conditionals gets no template and
the app lists the raw fields instead.

## Error maps and aggregation

Each module declares its own errors in one header, `sys_error_<module>.h`, kept in the module's **`errors/` folder**:

- `SYS_ERROR_<MODULE>_MAP(X)`: tags as `X(tag, id, level, struct)`: stable ID in the module's domain (`0xDDnn`), default severity (`se_level_e`) and payload struct;
- `SYS_<MODULE>_OWNER_MAP(X)`: owners, whose high byte (`owner & 0xFF00`) is the module's domain;
- `SYS_ERROR_<MODULE>_LOGGER_MAP(X)` plus `LOG_BODY_*`: optional readable payload descriptions.

`codes/sys_error_codes.h` includes every map and combines them into `SYS_ERROR_MAP` / `SYS_OWNER_MAP`, which generate the tag and owner enums, payload types, names and logger dispatch in `sys_error.h`.

| Module | Map | Domain |
|---|---|---|
| `sys_device` | `system/sys_device/errors/sys_error_dev.h` | `0xA1` |
| `sys_i2c` | `system/sys_i2c/errors/sys_error_i2c.h` | `0xA2` |
| `sys_io` | `system/sys_io/errors/sys_error_io.h` | `0xA3` |
| `sys_power` | `system/sys_power/errors/sys_error_power.h` | `0xA4` |
| `ble` | `system/ble/errors/sys_error_ble.h` | `0xA5` |
| `sys_interface` + decoders | `system/sys_interface/errors/sys_error_interface.h` | `0xA6` |
| `sys_buffers` | `system/sys_buffers/errors/sys_error_buffers.h` | `0xA7` |
| `sys_errors` | `codes/sys_error_base.h` | `0xA8` |
| `VM` | `VM/errors/sys_error_vm.h` | `0xA9` |
| `sys_actions` | `system/sys_actions/errors/sys_error_actions.h` | `0xAA` |
| `sys_event` | `system/sys_event/errors/sys_error_event.h` | `0xAB` |
| `sys_hbridge` | `system/sys_hbridge/errors/sys_error_hbridge.h` | `0xAC` |
| `sys_data_connector` | `system/sys_data_connector/errors/sys_error_data_connector.h` | `0xAD` |
| `runit` | `runit/errors/sys_error_runit.h` | `0xAF` |
| `sys_settings` | `system/sys_settings/errors/sys_error_settings.h` | `0xB0` |
| devices | `devices/devices/errors/devices_owners.h` | `0xD0` |

**Why include dirs, not `REQUIRES`.** Every module `REQUIRES sys_errors`, so `sys_errors` can't require them back (component cycle). It lists each `errors/` folder as a plain include dir in its `CMakeLists.txt` instead. The maps are pure data (X-macros), not code dependencies, so this is safe.

**Why a separate `errors/` folder.** The include dirs of `sys_errors` are public: every component that includes `sys_error.h` can also include whatever sits in them. If the maps lived in a module's `include/`, that module's whole API would leak to everyone. That once hid a real `ble` → `sys_data_connector` dependency. An `errors/` folder holds only error maps, so nothing else leaks.

**Rules for a map header:**
- Only data: X-macro maps and `LOG_BODY_*` macros.
- No includes beyond `<stdint.h>` / `<stdio.h>`: it's parsed early in the `sys_error.h` include chain, before `err_h` exists.
- A description that needs another module's names forward-declares just those symbols as `extern` (see `sys_error_dev.h`).
- **Name the IDs in a payload for the app.** Put an annotation right after the field's `;`. It must be a block comment, because the maps are one-line macros. For example: `struct { uint8_t dev_id; /*@id device*/ uint8_t mode; /*@enum-ref sys_io_mode_e*/ }`.
  - `/*@enum-ref <enum>*/` names a `//#ref-enum` enum.
  - `/*@id <kind>*/` names a value from another catalog. The kinds:
    - `device`: board device ID;
    - `error-tag`, `error-owner`, `error-level`;
    - `rx-class`: command class byte;
    - `rx-packet <class field>`: command packet byte; the class byte is in the named field;
    - `contract-feature <contract field>`: device contract feature ID (`SYS_DEV_FEATURE_ID`); the contract type is in the named field. Its names come from the feature tables marked `//@contract-features $SYS_DEVICE_CONTRACT_<X>` (`sys_io.c`, `sys_power.c`, `sys_hbridge.c`); a new contract needs one;
    - `vm-block-type`;
    - `esp-err`: an `esp_err_t`.
  - The app then prints `device 12 (INA3221)` instead of `device 12`. `generate-errors.py` rejects an unknown enum or kind. Keep the annotation when moving or reformatting the field (conventions §6).

**Adding a module's errors:**
1. Create `<component>/errors/sys_error_<module>.h`.
2. Pick an unused domain byte (table above).
3. Include the header in `codes/sys_error_codes.h`, and add its maps to `SYS_ERROR_MAP` / `SYS_OWNER_MAP` / the logger map.
4. Add the folder to `sys_errors/CMakeLists.txt`.
5. Only if the domain gets a fault hook, add it to `dispatch_domain()` in `sys_error_handler.c`.
6. Regenerate the app's tables: `python data-structures/auto-annotations/errors/generate-errors.py` (also after adding or changing any tag, owner or `LOG_BODY`).

**Expected build warnings.** ESP-IDF's component check reports each of these folders once ("Include directory … belongs to component X but is being used by component sys_errors"): 16 warnings, one per `errors/` folder. They are expected. Any other project warning is new and must be fixed. Adding a tag changes the schema ID (see "Logging and telemetry"); adding an owner doesn't.

## Files and verification

- `sys_error.c`: pool, release, bounded traversal, metadata.
- `sys_error_handler.c`: synchronous policy dispatch.
- `sys_error_log.c`: ESP logging hook, formatting, sink send.
- `enc_sys_errors.h`: private binary chain encoder.
- `include/sys_error.h`: constructors and ownership API.
- `include/sys_error_hooks.h`: optional domain hooks.
- `codes/sys_error_codes.h`: aggregate module tag/owner/logger maps (from each module's `errors/` folder, see above).

There is no test target: the host test (`tools/tests/test_sys_errors.py`) and the
firmware self-tests were removed in commit `47207d3`.

## Error Lifecycle & Call Tree Architecture

### 1. High-Level Flowchart

```mermaid
flowchart TD
    A["Error Origin (Driver / Subsystem / VM)"] -->|"SE_FAIL / SE_WRAP_ERR"| B["SE_push_to_handler(err)"]

    subgraph Phase1["Phase 1: Inspection & Chain Collection"]
        B --> C["SE_collect_chain()"]
        C --> D{"in_handler or corrupt?"}
        D -->|Yes| E["Diagnostics Only (Skip Policies)"]
    end

    subgraph Phase2["Phase 2: Attribution & Policy Dispatch"]
        D -->|No| F["Iterate Nodes in Error Chain"]
        F --> G{"Node has Device ID?"}

        %% Device Policy Path
        G -->|Yes| H["sys_device_report_error_with_level()"]
        H --> I{"importance NONE, or noncritical level below threshold?"}
        I -->|Yes| J["Skip device response"]
        I -->|No| K["Lookup action_id at original severity"]
        K --> L["registered device error policy (runit_device_policy)"]
        L --> M{"action_id != 0?"}
        M -->|Yes| N["sys_actions_invoke(action_id)"]
        L --> O{"level == CRITICAL?"}
        O -->|Yes| P["runit_system_fault()"]
        P --> P1["vm_exec_fault_latch()"]
        P --> P2["vm_exec_stop()"]
        P --> P3["sys_device_suspend_all()"]

        %% Domain Fault Hook Path
        F --> Q["dispatch_domain(node, err)"]
        Q --> R["sys_<domain>_handle_fault(node, err)"]
        R -->|VM| R1["sys_vm_handle_fault -> vm_exec_stop()"]
        R -->|BLE| R2["sys_ble_handle_fault -> sys_ble_publish(FAILURE)"]
        R -->|Actions| R3["sys_actions_handle_fault -> abort recording"]
        R -->|Interface| R4["sys_interface_handle_fault -> suspend RX"]
        R -->|Power/I2C/IO/Buffers| R5["Hardware containment / bus reset"]

        %% Fallback System Hook
        F --> S{"CRITICAL & Unhandled?"}
        S -->|Yes| T["registered system hook (runit_system_hook)"]
    end

    subgraph Phase3["Phase 3: Baseline Transport & Logging"]
        E --> U["SE_log(err) -> error log task -> SE_send(err)"]
        Phase2 --> U
        U --> V["se_log_error_chain()"]
        V --> V1["sink.send_log() (runit: logs connector)"]
        V --> V2["ESP_LOGE() (Serial Mirror)"]
        U --> W["SE_send_error_raw()"]
        W --> W1["enc_sys_errors_encode_chain()"]
        W1 --> W2["sink.send_packet() (runit: errors connector)"]
        W2 --> W3["ble_provider_send() -> sys_ble_char_send()"]
    end

    subgraph Phase4["Phase 4: Cleanup"]
        U --> X["SE_release(err)"]
    end
```

### 2. Detailed Sequence & Call Tree Diagram

```mermaid
sequenceDiagram
    autonumber
    actor Caller as Caller Task (e.g. AP33772S Driver)
    participant Core as sys_error.c
    participant Handler as sys_error_handler.c
    participant SysDev as sys_device.c
    participant Policy as runit_error_policy.c
    participant Actions as sys_actions.c
    participant VM as vm_exec.c
    participant Domain as sys_<domain>_handle_fault
    participant Log as sys_error_log.c
    participant Conn as sys_data_connector.c
    participant BLE as sys_ble_stack.c

    %% 1. Raising
    Note over Caller, Core: Step 1: Error Generation & Chaining
    Caller->>Core: SE_create(owner, tag, payload_size)
    Caller->>Core: SE_wrap(outer_err, cause_err)
    Caller->>Handler: SE_push_to_handler(err)

    %% 2. Collection & Attribution
    Note over Handler, SysDev: Step 2: Inspection & Device Attribution
    Handler->>Core: SE_collect_chain(err, nodes[], &complete)
    loop For each node in chain
        Handler->>Handler: device_id_of(node, &dev_id)
        alt Node is attributed to a device
            Handler->>SysDev: sys_device_report_error_with_level(dev_id, level, node)
            SysDev->>SysDev: sys_device_get_by_id(dev_id)
            alt importance NONE, or noncritical level below threshold
                SysDev-->>Handler: NULL (no device response)
            else Admitted level
                SysDev->>SysDev: action_id = dev->actions[level]
                SysDev->>Policy: runit_device_policy(dev_id, level, action_id, node)

                opt action_id != 0
                    Policy->>Actions: runit_invoke_action(action_id) -> sys_actions_invoke(scope, id)
                end

                opt level == SE_LEVEL_CRITICAL
                    Policy->>Policy: runit_system_fault(dev_id, node)
                    Policy->>VM: vm_exec_fault_latch(dev_id, owner, tag)
                    Policy->>VM: vm_exec_stop()
                    Policy->>SysDev: sys_device_suspend_all()
                end
                Policy-->>SysDev: policy_response
                SysDev-->>Handler: response
            end
        end

        %% 3. Domain Dispatch
        Note over Handler, Domain: Step 3: Domain Specific Fault Handling
        Handler->>Handler: dispatch_domain(node, err)
        Handler->>Domain: sys_<domain>_handle_fault(node, err)
        Domain-->>Handler: domain_response

        opt level == CRITICAL and system not yet handled
            Handler->>Policy: runit_system_hook(node, err)
        end
    end

    %% 4. Baseline Logging & Telemetry
    Note over Handler, BLE: Step 4: Baseline Invariant (All Error Chains)
    Handler->>Log: SE_send(err)

    rect rgb(240, 245, 255)
        Note over Log, Conn: 4a. Text Expansion & Logging
        Log->>Log: se_log_error_chain(err)
        loop For each node
            Log->>Core: SE_describe_payload(tag, payload, desc)
            Log->>Conn: sink.send_log(line, len) (runit: logs connector)
            opt mirror_on_serial == true
                Log->>Log: ESP_LOGE(TAG, "%s", line)
            end
        end
    end

    rect rgb(240, 255, 245)
        Note over Log, BLE: 4b. Wire Encoding & Raw Transport
        Log->>Log: SE_send_error_raw(err)
        Log->>Core: enc_sys_errors_encode_chain(err, packet, max_len)
        Log->>Conn: sink.send_packet(packet, len) (runit: errors connector)
        Conn->>BLE: ble_provider_send(arg, frame, len)
        BLE->>BLE: sys_ble_char_send()
    end

    %% 5. Release
    Note over Handler, Core: Step 5: Allocator Reclamation
    Handler->>Core: SE_release(err)
```

### 3. Component Symbol & Call Reference Map

| Component / Step | Source File | Key Symbols / Functions |
| :--- | :--- | :--- |
| **Error Allocation & Chaining** | `sys_error.c` | `SE_create()`, `SE_wrap()`, `SE_collect_chain()`, `SE_release()` |
| **Handler & Central Dispatch** | `sys_error_handler.c` | `SE_push_to_handler()`, `device_id_of()`, `dispatch_domain()` |
| **Device Error Routing** | `components/system/sys_device/sys_device.c` | `sys_device_report_error_with_level()`, `sys_device_report_error()`, `sys_device_suspend_all()` |
| **App Coordinator Policy** | `components/runit/runit_error_policy.c` | `runit_error_wiring_init()`, `runit_device_policy()`, `runit_system_hook()`, `runit_system_fault()`, `runit_invoke_action()` |
| **Action Execution** | `components/system/sys_actions/sys_actions.c` | `sys_actions_invoke()` |
| **VM Fault Containment** | `components/VM/core/exec/vm_exec.c` | `vm_exec_fault_latch()`, `vm_exec_stop()`, `sys_vm_handle_fault()` |
| **Logging & Wire Telemetry** | `sys_error_log.c` | `SE_log()` (queue), error log task, `SE_send()`, `se_log_error_chain()`, `SE_send_error_raw()` |
| **Output Sink Binding** | `components/runit/runit_board_cfg.c` | `runit_board_error_sink_init()` → `SE_register_sink()` |
| **Bus Switchboard** | `components/system/sys_data_connector/sys_data_connector.c` | `sys_data_connector_send()` |

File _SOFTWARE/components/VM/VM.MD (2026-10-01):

# Virtual Machine (VM)

Related docs: [VM_EXEC.MD](VM_EXEC.MD) (the execution model and why), [VM_OBJ_ACCESS.MD](core/obj/VM_OBJ_ACCESS.MD) (object/accessor API with examples), [VM_OBJ_CONTRACTS.md](core/obj/VM_OBJ_CONTRACTS.md) (lifetime, ownership, mutation rules), [VM_PERF.MD](VM_PERF.MD) (hot-path measurements and decisions — history).

IMPORTANT: If you modify the source files in this component (`core/**`, `blocks/**`), you must update this documentation to reflect the changes.

## Overview

`VM` is the runtime for runIT's block-based scripting language. A program is compiled off-device into a flat description, uploaded wirelessly, and rebuilt here into a graph of **objects** (the data) wired to **blocks** (the behaviour), executed cyclically by a supervisor.

Three properties shape every decision in this component:

* **No dynamic allocation after load** — with one deliberate exception. The pool is heap-allocated once per upload, sized by the program itself; from then until the next upload every allocation is a bump within it. Individual objects are never freed; replacing a program resets the whole arena and rebuilds. This removes lifetime tracking, fragmentation and the allocation-failure path from the runtime entirely.

  The exception is `VM_BLK_CLONE`, which builds its destination on the heap through `vm_obj_dyn`. It allocates when the source schema changes, including tag identity. A matching destination is validated and refilled in place. Replacements are built and filled before publication, then the old tree is released. Dynamic owning links are shared, acyclic, and depth-bounded.
* **Each object's schema and permission flags are fixed after load.** Values, pointer links, and freshness can change at runtime. Clone replaces objects when a message schema changes; it never resizes an existing object. Block construction protects its output objects before execution starts.
* **Everything from the wire is untrusted.** Ids, counts, offsets and lengths arriving in an upload packet are validated before they reach storage, and the whole load path returns `err_h` chains rather than sentinels.

### Directory Map
```
components/VM/
├── CMakeLists.txt
├── VM.MD, VM_EXEC.MD, VM_PERF.MD
├── errors/
│   └── sys_error_vm.h          # VM owner map + error tag map + _OWNED error macros
├── blocks/                     # THE PALETTE — block types & dispatch tables
│   ├── vm_blocks.h             # type ids (VM_BLK_*), table declarations, vm_block_fn_for()
│   ├── vm_blocks_table.c       # g_vm_block_types[]: one entry per type (body, check, shape, state size)
│   ├── vm_block_expr.h         # EXPR (float) and EXPR_BIT (uint32) — RPN bytecode
│   ├── vm_block_branch.h       # IF (two-way) and SWITCH (n-way) flow routers
│   ├── vm_block_for.h          # FOR — span owner / loop runner
│   ├── vm_block_set.h          # SET — explicit copy, source -> destination
│   ├── vm_block_clone.h        # CLONE — copy building destination dynamically
│   ├── vm_block_edge.h         # EDGE — edge detector (rising, falling, both)
│   ├── vm_block_timer.h        # TIMER — timers (TON, TOF, TP + inverted), time units
│   ├── vm_block_io_set_level.h # IO_SET_LEVEL — drive a pin (sys_io)
│   ├── vm_block_io_toggle.h    # IO_TOGGLE — toggle a pin (sys_io)
│   ├── vm_block_latch.h        # LATCH — SR / RS bistable
│   ├── vm_block_periodic.h     # PERIODIC — "every N" tick
│   ├── vm_block_action.h       # ACTION — request a system action (queued)
│   └── vm_block_on_event.h     # ON_EVENT — start a chain on a matching system event
└── core/
    ├── errors/
    │   └── vm_errors.h/.c      # block/pin error builders
    ├── store/
    │   └── vm_store.h/.c       # THE storage API — per-load pool, bump arena, three id registries
    ├── obj/
    │   ├── vm_obj.h            # vm_obj_head_t / vm_obj_t / vm_obj_h, type widths, header helpers
    │   ├── vm_obj_build.h/.c   # vm_obj_create() / vm_accessor_create()
    │   ├── vm_obj_dyn.h/.c     # heap objects, refcounted, register + teardown
    │   └── vm_obj_access*.h/.c # accessors, payload resolution, typed get/set macros, copy/clone/link
    ├── block/
    │   ├── vm_block.h          # vm_block_data_t, pin access, EN/ENO, cfg.rt, spans, BLOCK_CALL
    │   ├── vm_block_build.h/.c # vm_block_create(): wiring resolution + verify
    │   ├── vm_block_helpers.h/.c # shape checks, optional pins, gates, user-mutation boundary
    │   └── vm_block_run.c      # what a block body reaches for: ask, claim a span
    ├── exec/
    │   ├── vm_event.h/.c       # routed sys_event events — queue + per-pass snapshot
    │   ├── vm_override.h/.c    # runtime variable updates between scan loops
    │   └── vm_exec.h/.c        # the supervisor: pass loop, dispatch, spans, watchdog, control, action requests
    ├── loader/
    │   ├── vm_loader.h/.c      # load state machine, wire-facing validation
    │   └── vm_wire.h           # packed wire records of class 0x04 and telemetry (published)
    ├── retain/
    │   └── vm_retain.h/.c      # retained values: capture, save (retain task), restore by name
    └── sub/
        └── vm_sub.h/.c         # telemetry subscriptions (packet 0x47)
```

The groups are stacked bottom-up: `obj` builds on `store`, `block` on `obj`, and `exec` on `block`. The loader owns the program lifecycle. The store's teardown also calls the dynamic allocator so resetting storage always reclaims both allocation domains.

`blocks/` sits outside `core/` and depends on it, never the reverse. The supervisor dispatches through the *declarations* in `vm_blocks.h` and never learns what is in the tables — which is what keeps `core/` free of `sys_io` and every other driver a real block pulls in. Anything above the VM's layer (system actions) is reached through a function the application registers (`vm_exec_register_action_request()`), never by include.

**Every include across the project is by bare filename** — `#include "vm_obj.h"`, never `"obj/vm_obj.h"`. Each group is on the include path instead (see `CMakeLists.txt`), so this tree is a reading aid and regrouping it again later touches no source file. The one path that is spelled out is `../VM/errors` in `sys_errors/CMakeLists.txt`, which reaches the error map without a circular `REQUIRES`.

The upload decoder table (`dec_vm_loader.h`, class `0x04`) lives in `components/codecs/decoders/` — see [[CODECS.MD]].

---

## Object Model

The current lifetime, ownership, schema, write-policy, and publication contracts
are specified in [VM_OBJ_CONTRACTS.md](core/obj/VM_OBJ_CONTRACTS.md).

An object is a fixed 4-byte header followed by a flexible payload:

```c
typedef struct __attribute__((aligned(4))) vm_obj_head_t {
  uint16_t payload_size;      // value length in bytes
  struct { uint8_t obj_t : 4; uint8_t name_size : 4; } d;
  struct {
    uint8_t mutable : 1;      // anything may write it
    uint8_t upd : 1;          // published this pass
    uint8_t upd_resetable : 1;
    uint8_t tagged : 1;       // name present
    uint8_t retentive : 1;    // persist to NVS
    uint8_t dynamic : 1;      // registered heap allocation
    uint8_t usr_protected : 1;// user writes denied; internal writes still allowed
    uint8_t _pad : 1;
  } f;
} vm_obj_head_t;              // _Static_assert'd at 4 bytes

typedef struct vm_obj_t { vm_obj_head_t head; uint8_t payload[]; } vm_obj_t;
typedef vm_obj_t* vm_obj_h;   // opaque handle, same convention as err_h
```

**The name lives at the tail**, at `payload[payload_size]` onward — not as a prefix. This is why `vm_obj_get_payload_ptr()`/`vm_obj_get_payload_size()` need no branch on `tagged`: the value always starts at `payload[0]` and always runs `payload_size` bytes, whether the object is named or not. Only cold paths (`vm_obj_get_tag()`, NVS keying, telemetry decode) ever touch the name. `name_size` living in the header rather than as a length byte in the tail means the tag needs no length prefix at all.

Total footprint is `sizeof(head) + payload_size + name_size` (`vm_obj_get_total_size()`), which is also the stride an arena walker uses.

### Types and widths

```c
VM_OBJ_NONE, VM_OBJ_PTR, VM_OBJ_U8, VM_OBJ_U32, VM_OBJ_I32,
VM_OBJ_F, VM_OBJ_B, VM_OBJ_STR
```

Two parallel tables in `vm_obj.h`: `vm_obj_type_sizes[]` (bytes) and `vm_obj_type_shifts[]` (log2 of the same). **Every width is a power of two**, so "how many items fit in `payload_size` bytes" is a shift, not a divide — the single hottest operation in accessor resolution, and one the compiler cannot strength-reduce itself because the width comes from a runtime lookup. Adding a non-power-of-two type would silently truncate; it needs a matching shift entry.

`VM_OBJ_STR` is **an array of chars**, not a distinct string abstraction: one byte per element, no terminator implied by the type. A whole-object accessor gives the buffer, an indexed one gives a single character, and everything that works on a `VM_OBJ_U8` array works here. It stays a separate type from `VM_OBJ_U8` because the type is what tells a client how to render the bytes — which is also why `vm_obj_copy_content()` refuses `STR` → `U8` despite the identical width.

**A new type needs an arm in every value-path switch**, not just the two tables: `vm_internal_scalar_type()`, `VM_INTERNAL_LOAD_SCALAR()`, `vm_internal_store_inline()` and `payload_as_index()`. A missing case is not a compile error — it falls to `default` and reads or writes **0**, which is indistinguishable from a genuinely empty value. `VM_OBJ_STR` once shipped that way, reading back 0.

### Nested objects

There is no composite type. A parent is a `VM_OBJ_PTR` array whose elements are `vm_obj_h` values pointing at children — the same shape Python lists, Java jagged arrays and cJSON use. Children are independently typed, tagged, flagged and addressable.

Consequences worth knowing:
* **Pointer payloads are never portable.** They are addresses in this boot's arena. `retentive` is rejected outright for `VM_OBJ_PTR` at creation, `vm_obj_copy_content()` **walks** a PTR array rather than copying its bytes — so a copy never duplicates an address — and the upload protocol carries **child ids**, never addresses.
* Building is order-dependent: children first, then the parent, then link.

---
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

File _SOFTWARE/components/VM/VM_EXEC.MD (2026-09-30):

# VM Execution Model & Target Look

This document specifies the execution model and runtime semantics for the runIT VM:
- **Core Engine**: Implemented in `core/exec/` and `core/block/` (see [[VM.MD]]).
- **Execution Units**: Topological block-by-block scan passes with span jumps for nested flow control.
- **Palette**: One table in `blocks/` (15 block types, [[VM.MD]] "What ships today"), published for the app as one descriptor per block in `data-structures/vm/blocks/`.

This is the model's specification, and it is ahead of the code in places. What is built and what is still design:
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

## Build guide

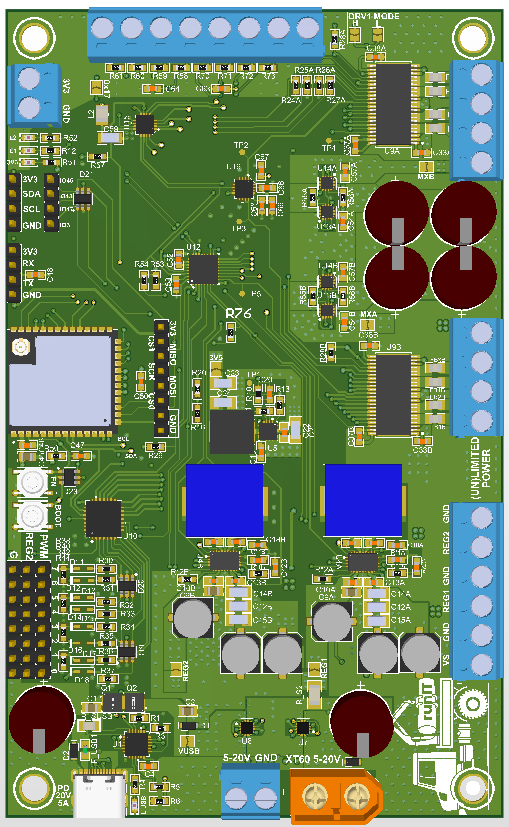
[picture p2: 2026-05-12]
_HARDWARE/Project Outputs for PBL4_2026L_runIT/PCB 3D Print/PCB.png

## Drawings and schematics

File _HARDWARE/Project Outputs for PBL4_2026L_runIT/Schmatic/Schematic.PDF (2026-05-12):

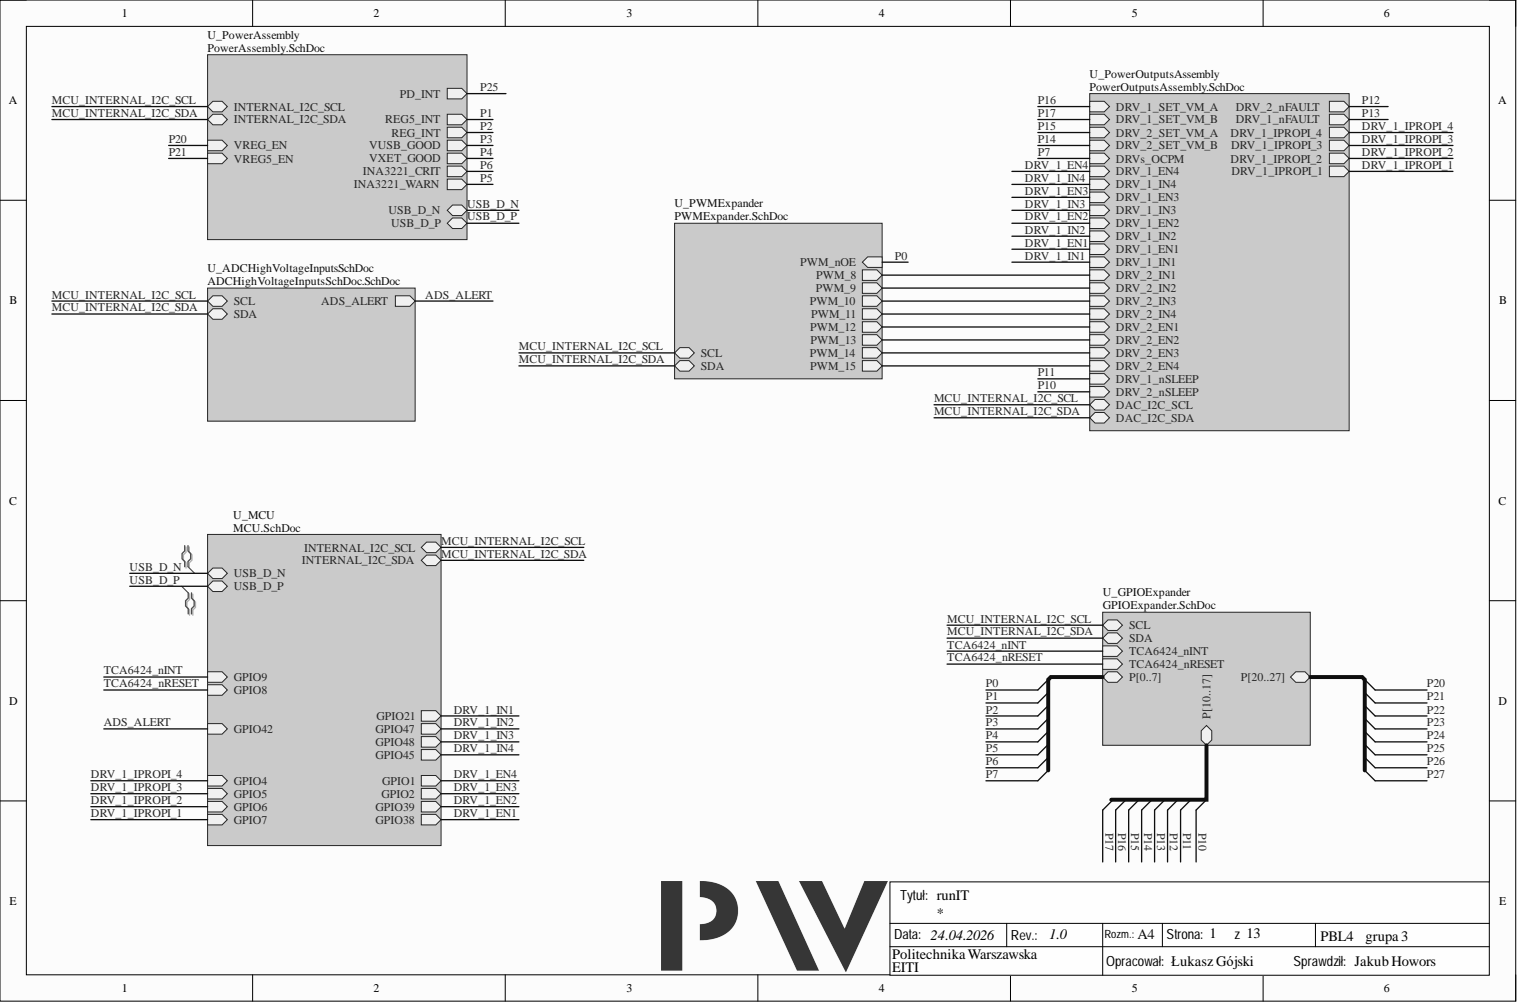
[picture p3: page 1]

Data : 4.04 . 6 | Rev.: . | Rozm.: A | Strona : z | PBL gru p a
P olite c h nik a Wa r s z a w s k a EIT I | | O pracował : Ł u k asz G ój s ki S prawdz ił : Ja k u b Ho w o r s

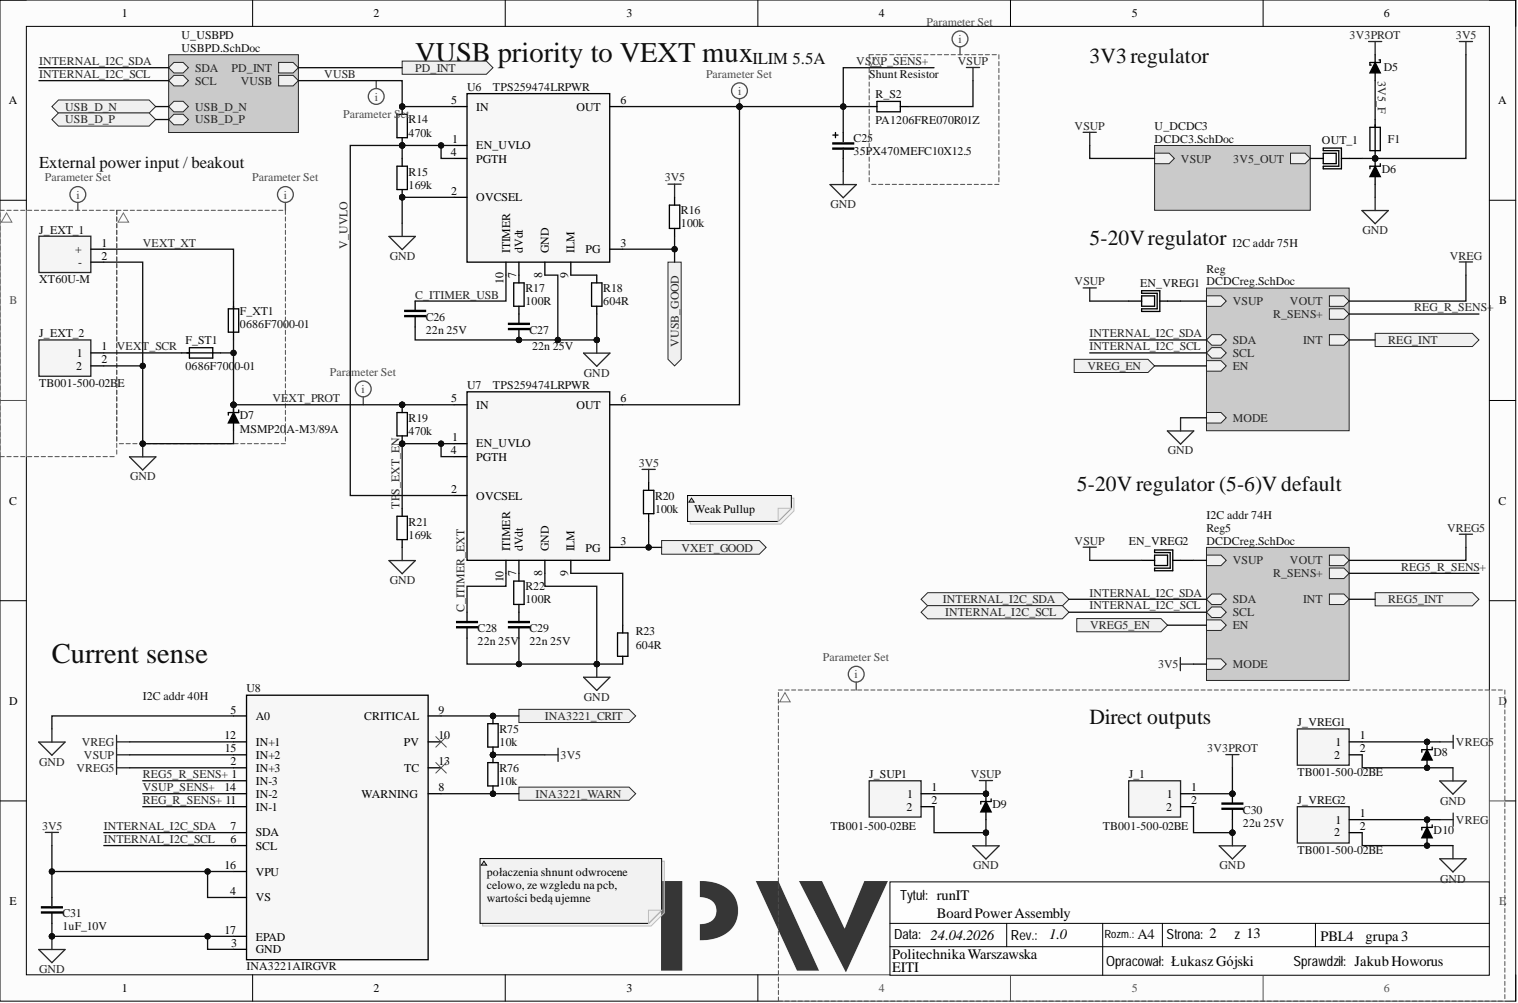
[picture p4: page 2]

VUSB priority to VEXT mux VUSB

External power input / beakout
Parameter Set

D7 | EN_UVLO 1

PGTH 4

połaczenia shnunt odwrocene
celowo, ze wzgledu na pcb,
wartości bedą ujemne

Data: 24.04.2026 | Rev.: 1.0 | Rozm.: A4 | Strona: 2 z 13 | PBL4 grupa 3
Politechnika Warszawska EITI | | Opracował: Łukasz Gójski Sprawdził: Jakub Howorus

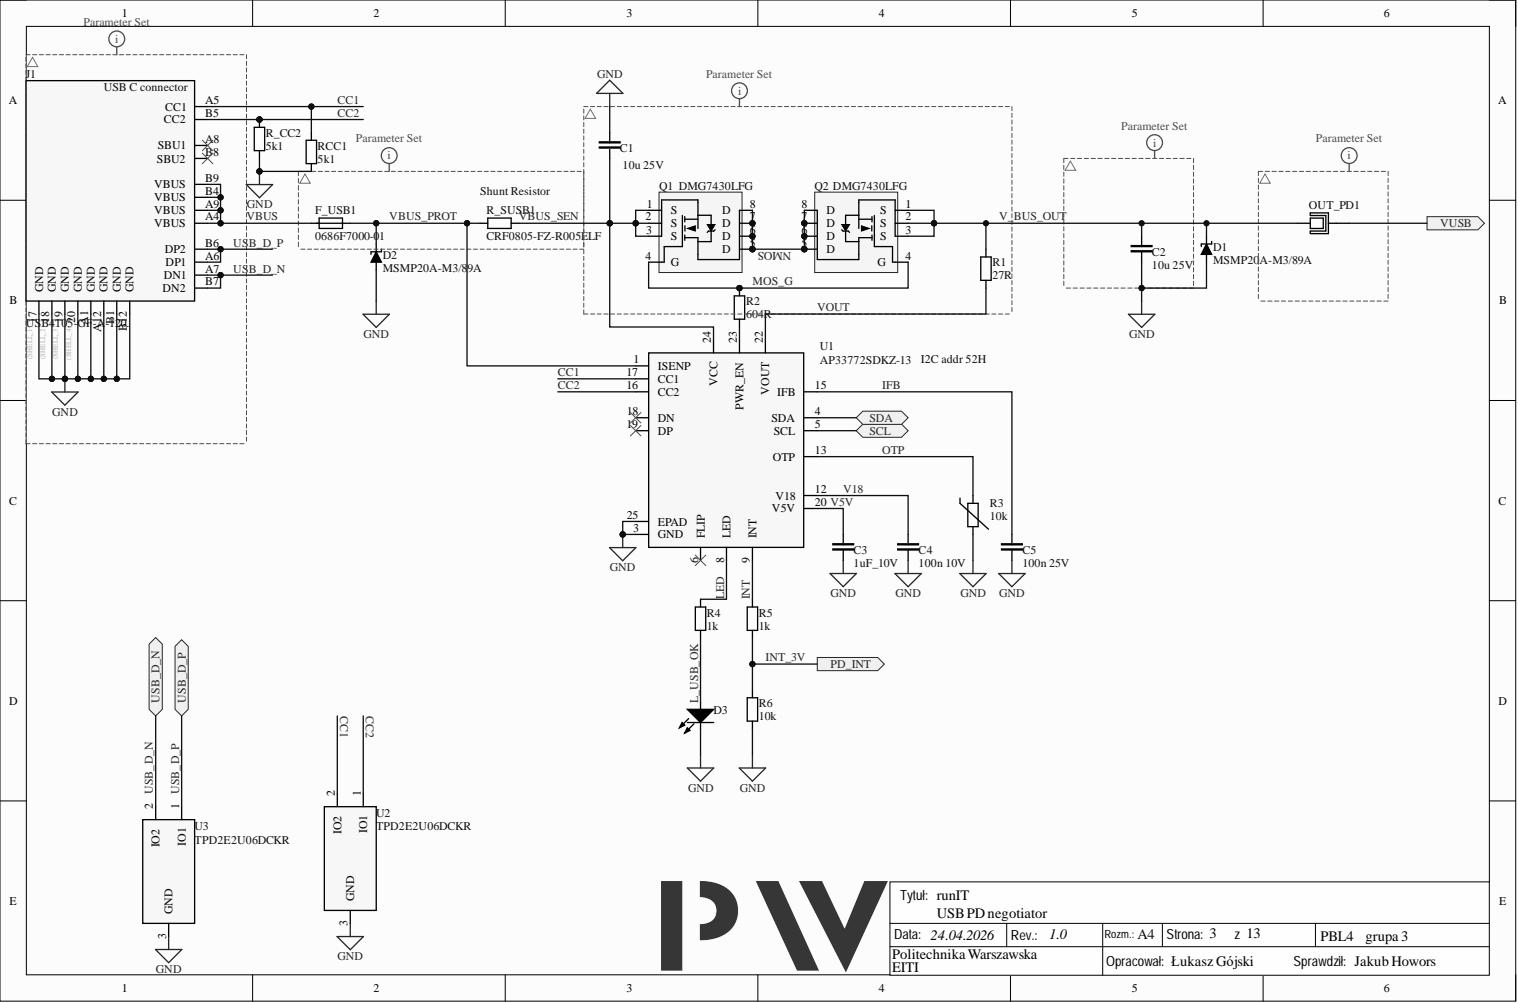
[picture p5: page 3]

GND 20 (SHELL_4) GND 19 (SHELL_3) GND 18 (SHELL_2) GND 17 (SHELL_1) J1

VOUT

V18
V5V

Data: 24.04.2026 | Rev.: 1.0 | Rozm.: A4 | Strona: 3 z 13 | PBL4 grupa 3
Politechnika Warszawska EITI | | Opracował: Łukasz Gójski Sprawdził: Jakub Howors

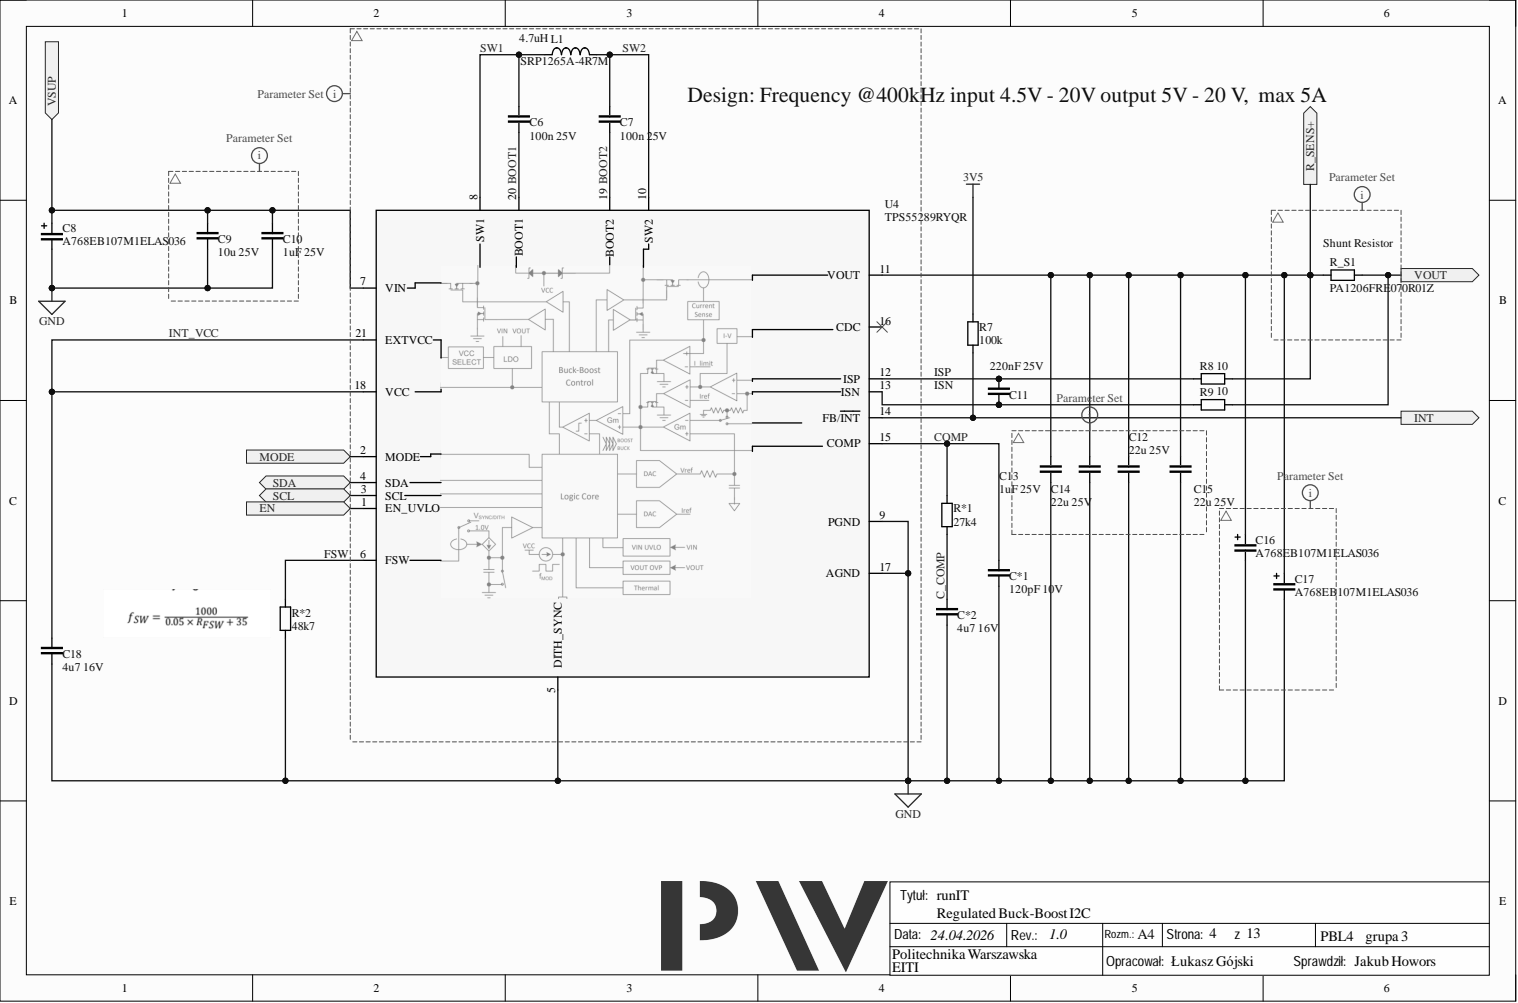
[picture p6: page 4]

1 3 | ISN

MO D E SD A SCL E N FSW | | 2 | C1 1 | Parameter Set

1 | SCL 3 SDA 4

Data : 4.04 . 6 | Rev.: . | Rozm.: | Strona : z | PBL gru p a
P olite c h nik a Wa r s z a w s k a EIT I | | O pracował : Ł u k asz G ój s ki S prawdz ił : Ja k u b Ho w o r s

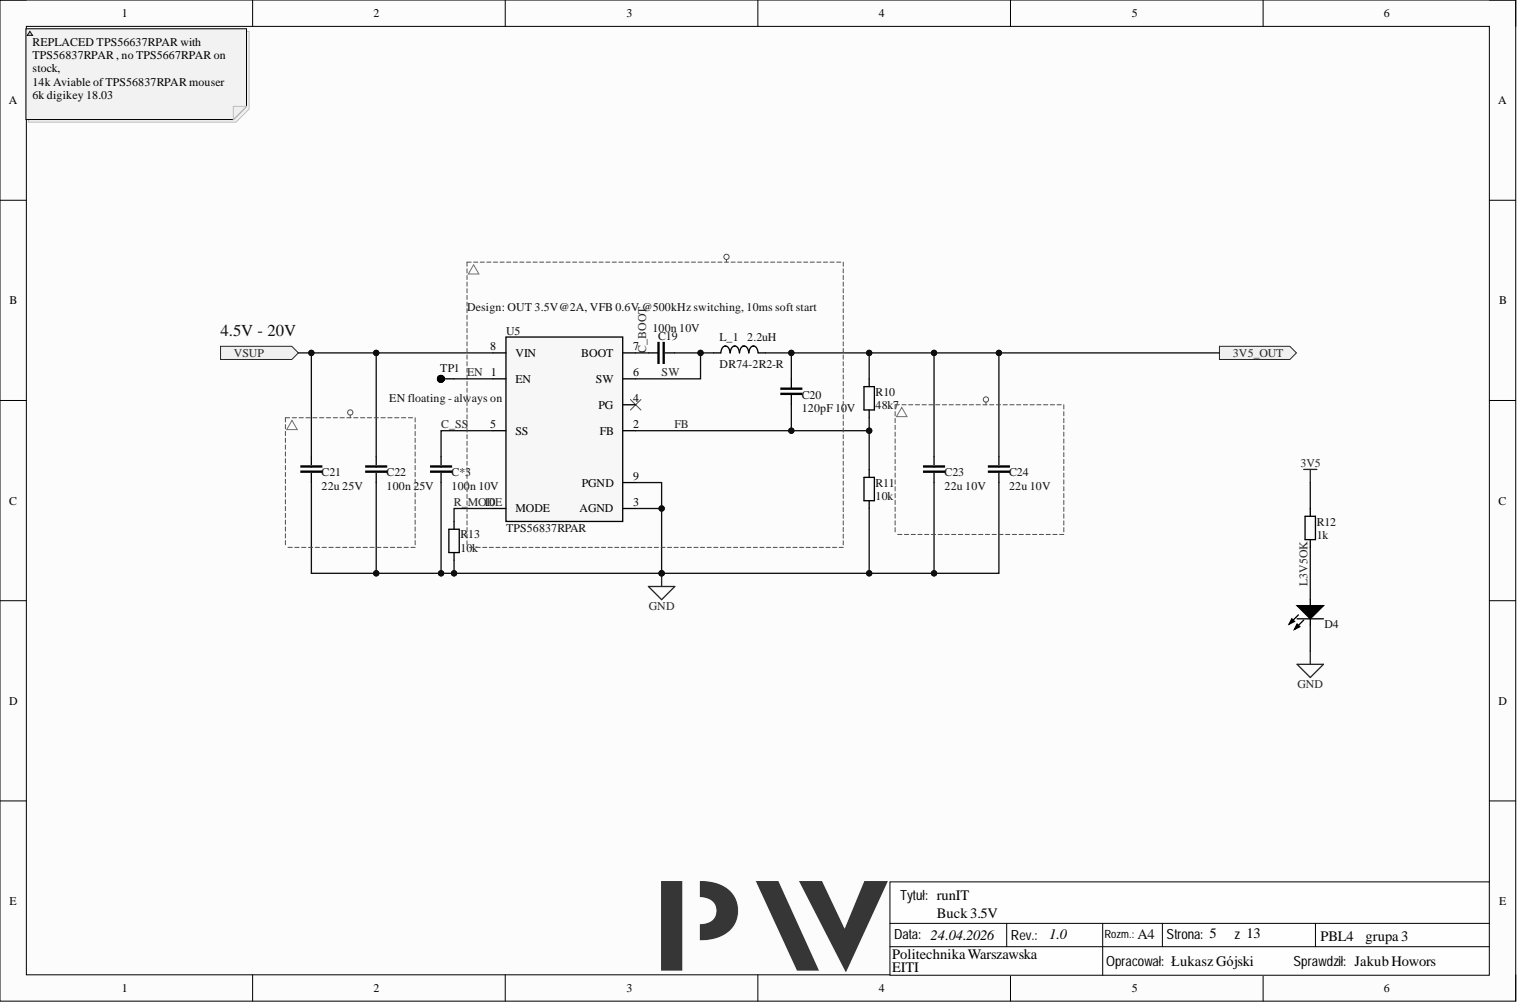
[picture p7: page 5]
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

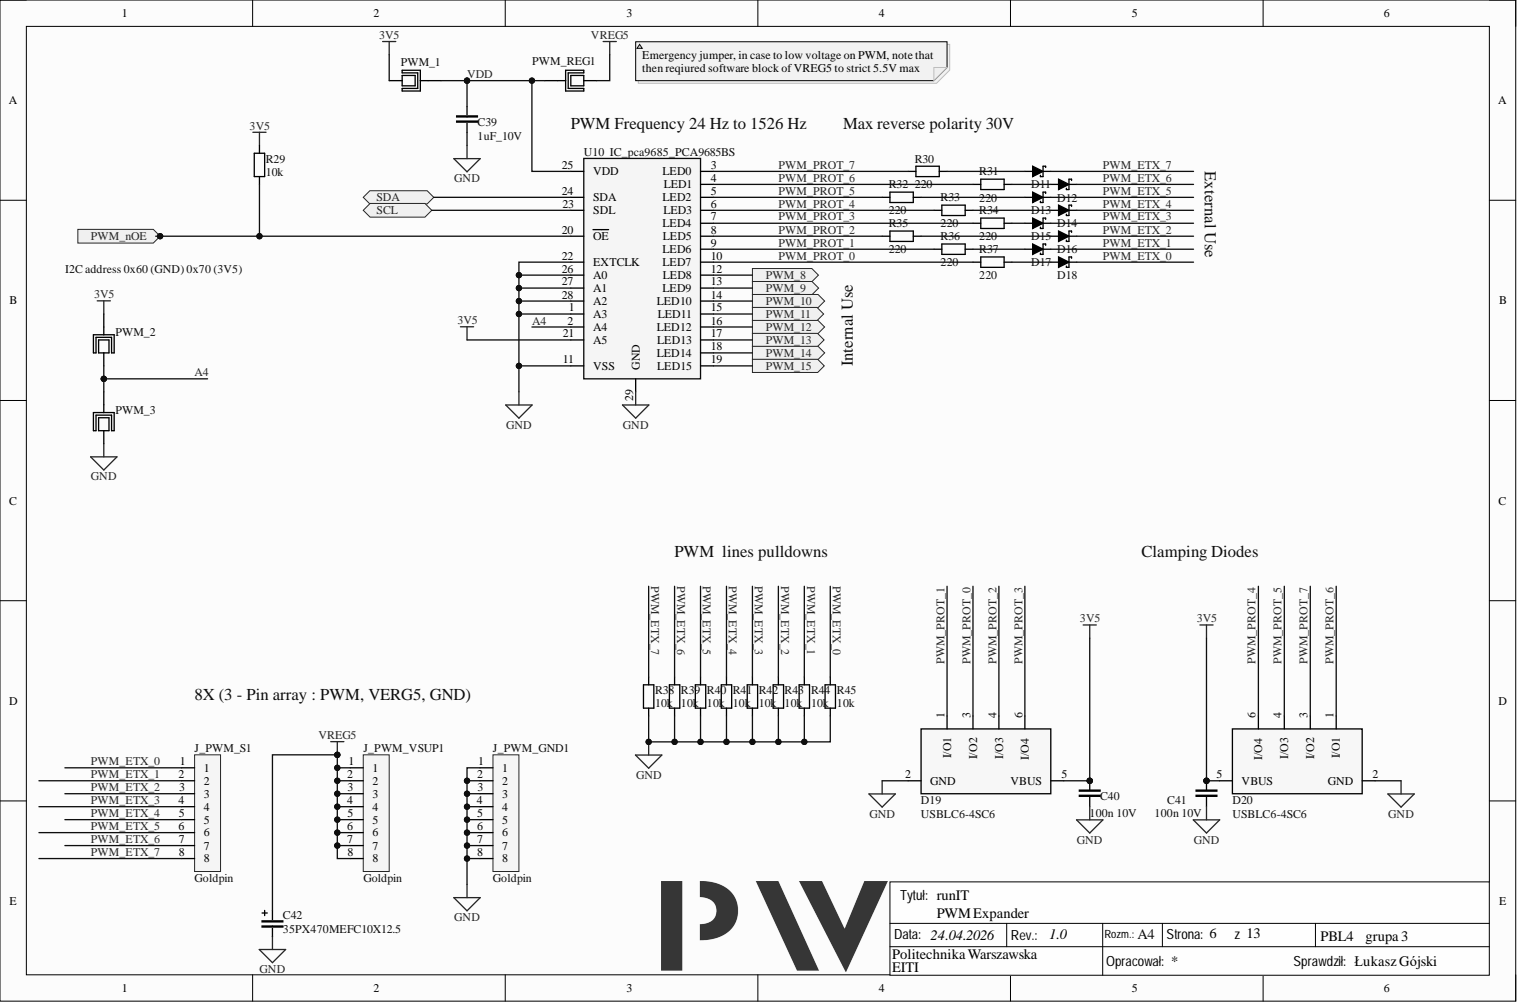
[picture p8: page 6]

Emergency jumper, in case to low voltage on PWM, note that
then reqiured software block of VREG5 to strict 5.5V max

PWM Frequency 24 Hz to 1526 Hz

8X (3 - Pin array : PWM, VERG5, GND)

Data: 24.04.2026 | Rev.: 1.0 | Rozm.: A4 | Strona: 6 z 13 | PBL4 grupa 3
Politechnika Warszawska EITI | | Opracował: * Sprawdził: Łukasz Gójski

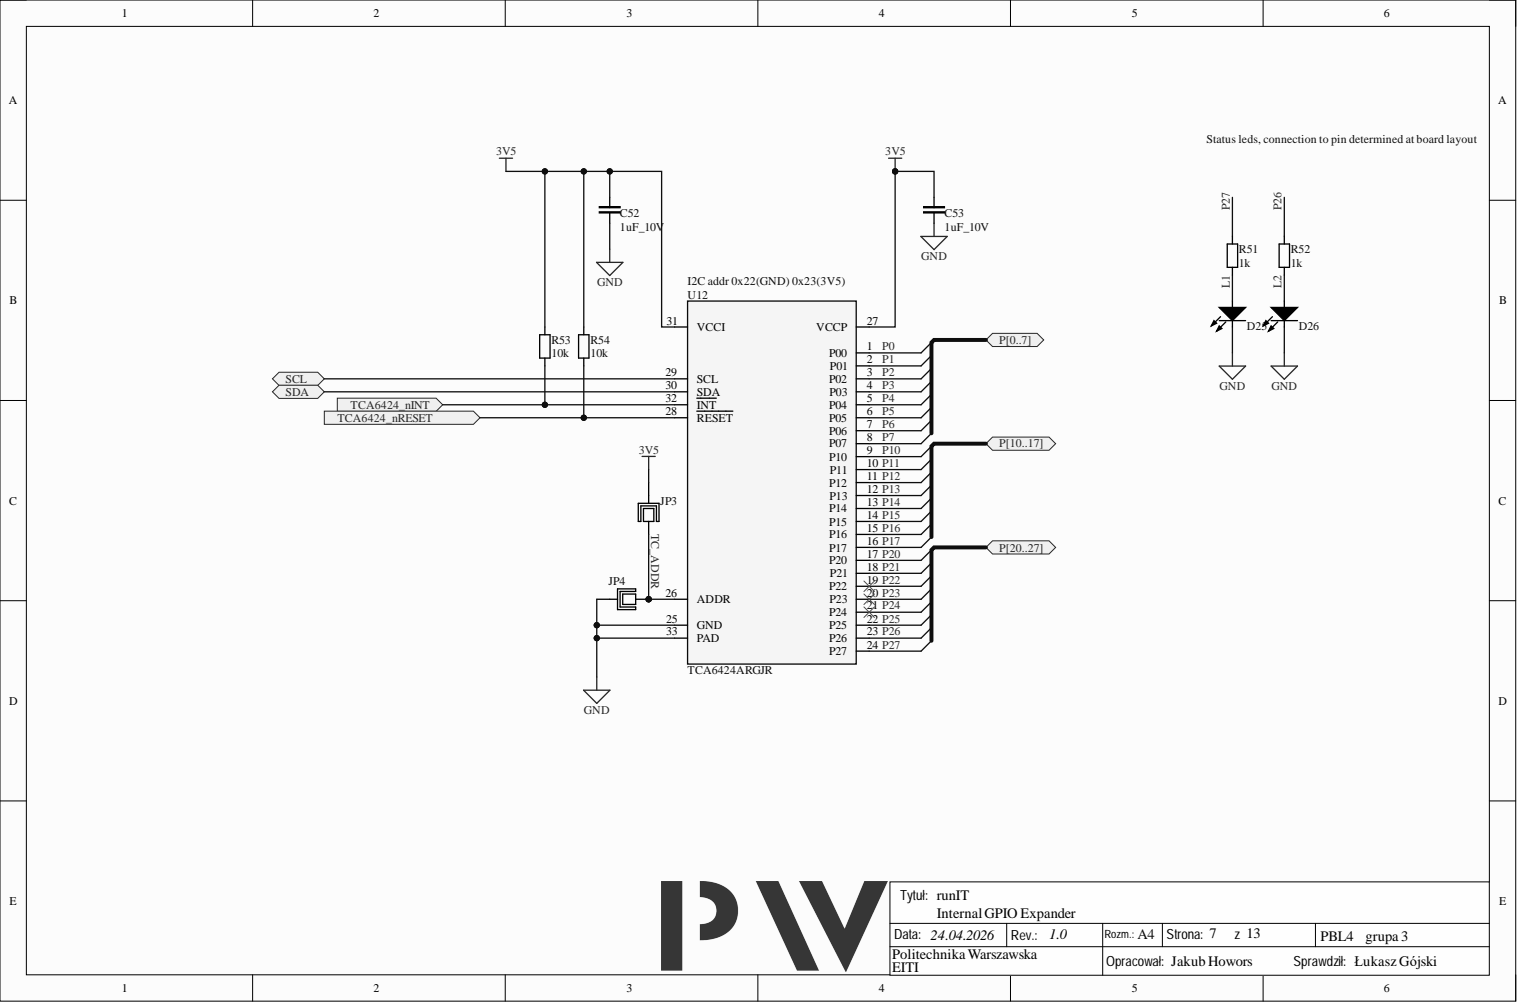
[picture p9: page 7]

Data : 4.04 . 6 | Rev.: . | Rozm.: | Strona : z | PBL gru p a
P olite c h nik a Wa r s z a w s k a EIT I | | O pracował : Ja k u b Ho w o r s S prawdz ił : Ł u k asz G ój s ki

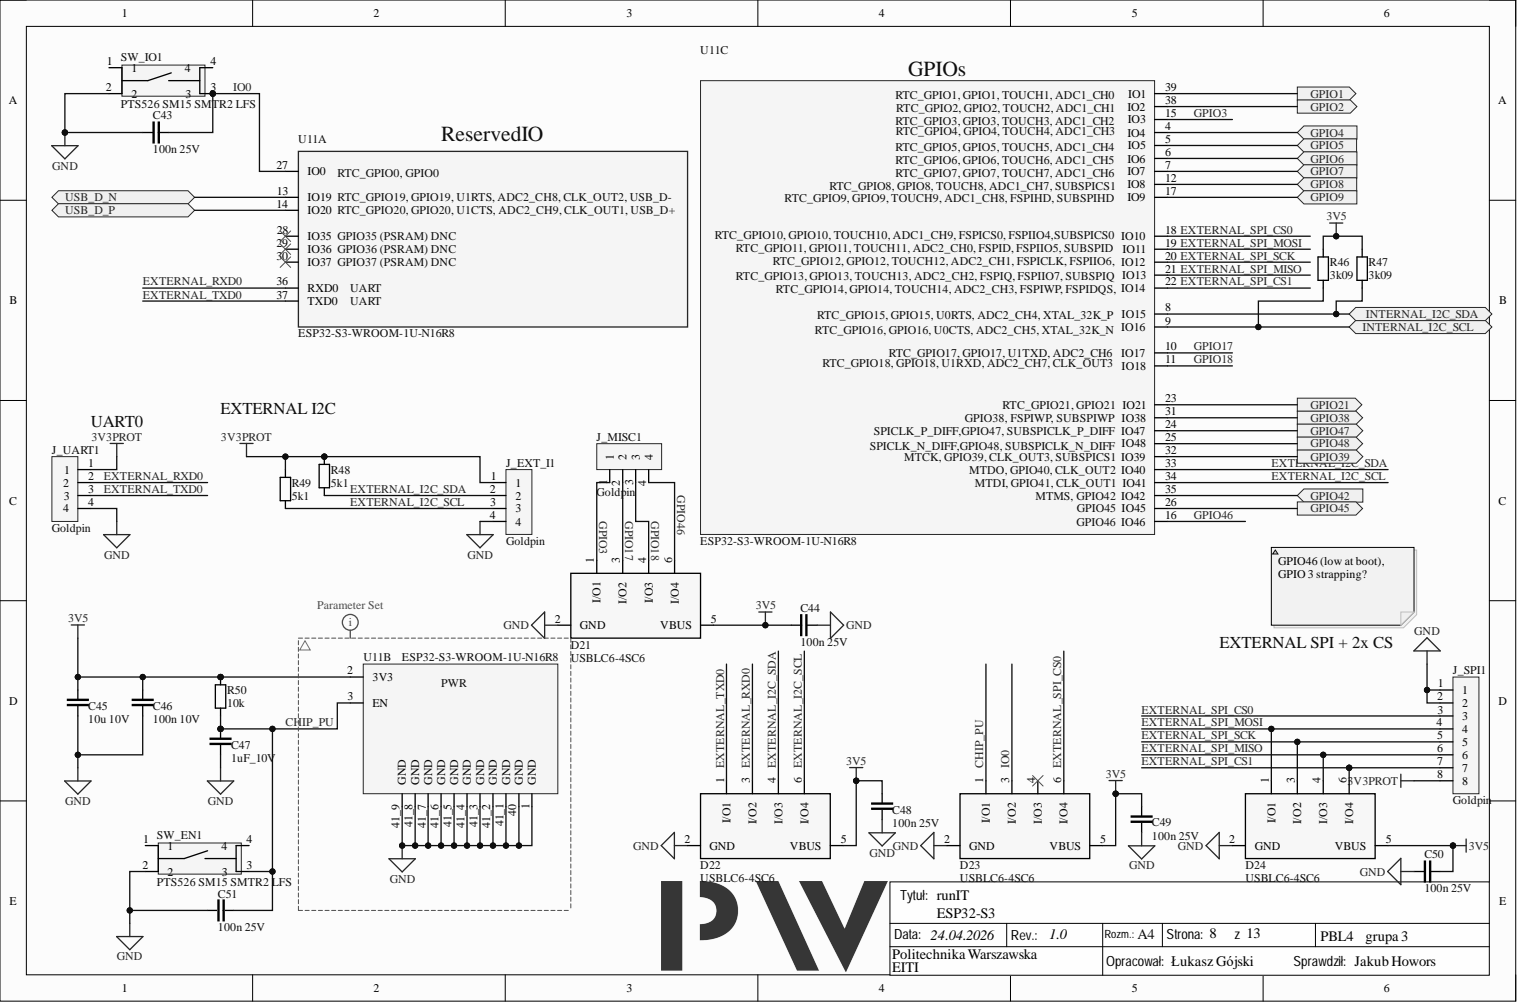
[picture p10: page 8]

GND 1 GND 40 GND 41_1 GND 41_2 GND 41_3 GND 41_4 GND 41_5 GND 41_6 GND 41_7 GND 41_8 GND 41_9

Data: 24.04.2026 | Rev.: 1.0 | Rozm.: A4 | Strona: 8 z 13 | PBL4 grupa 3
Politechnika Warszawska EITI | | Opracował: Łukasz Gójski Sprawdził: Jakub Howors

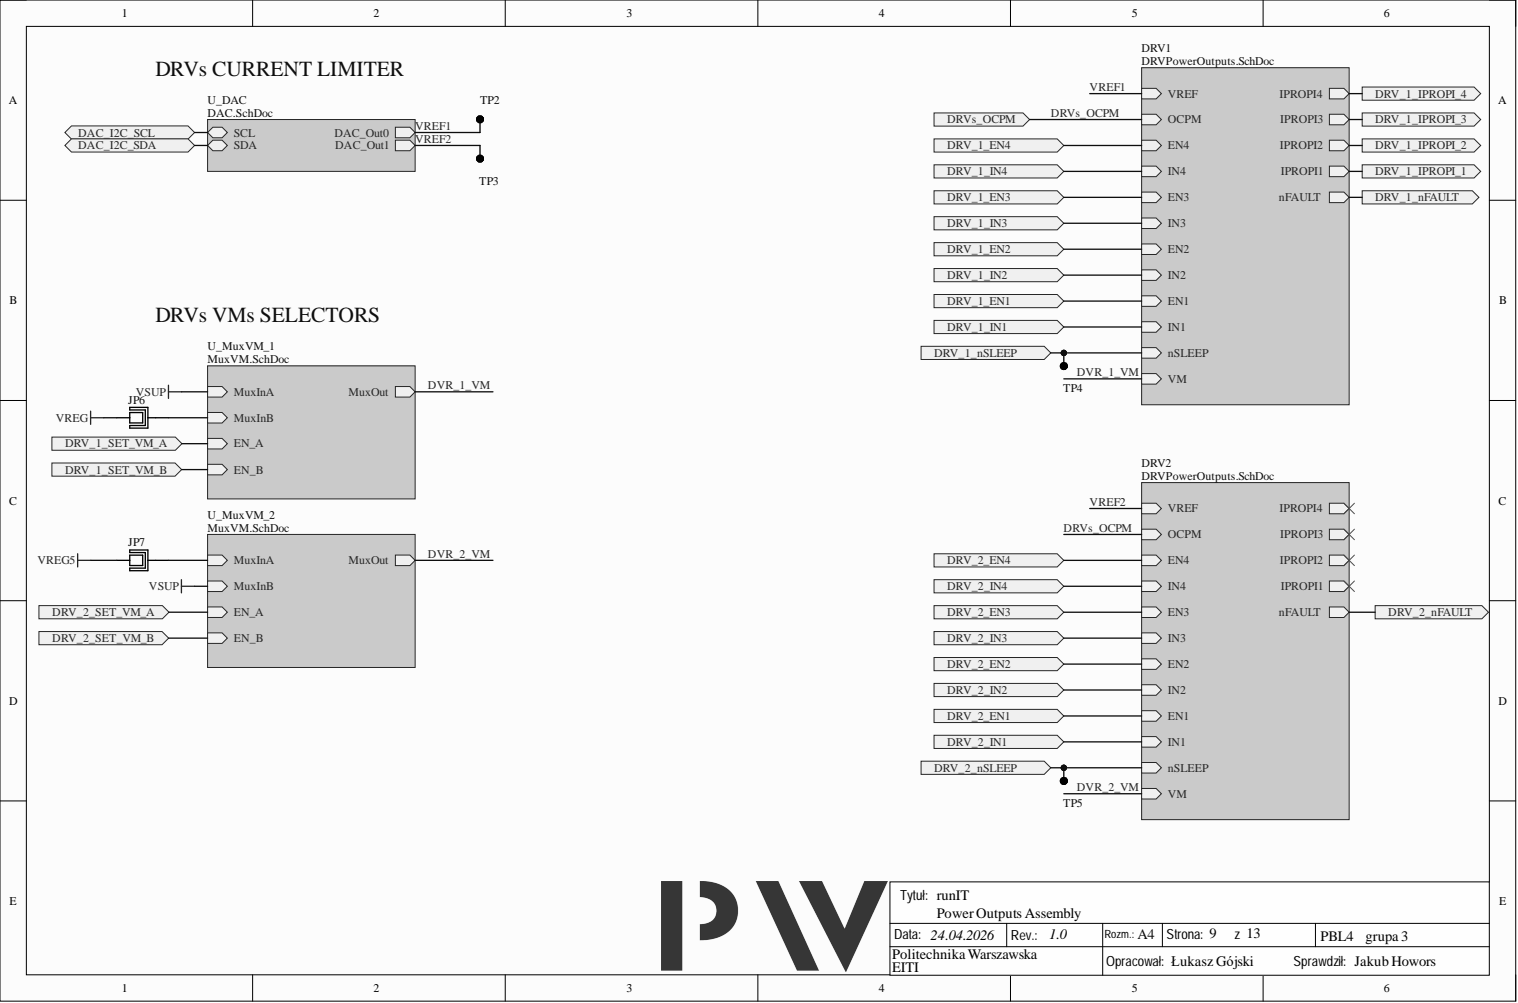
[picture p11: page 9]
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

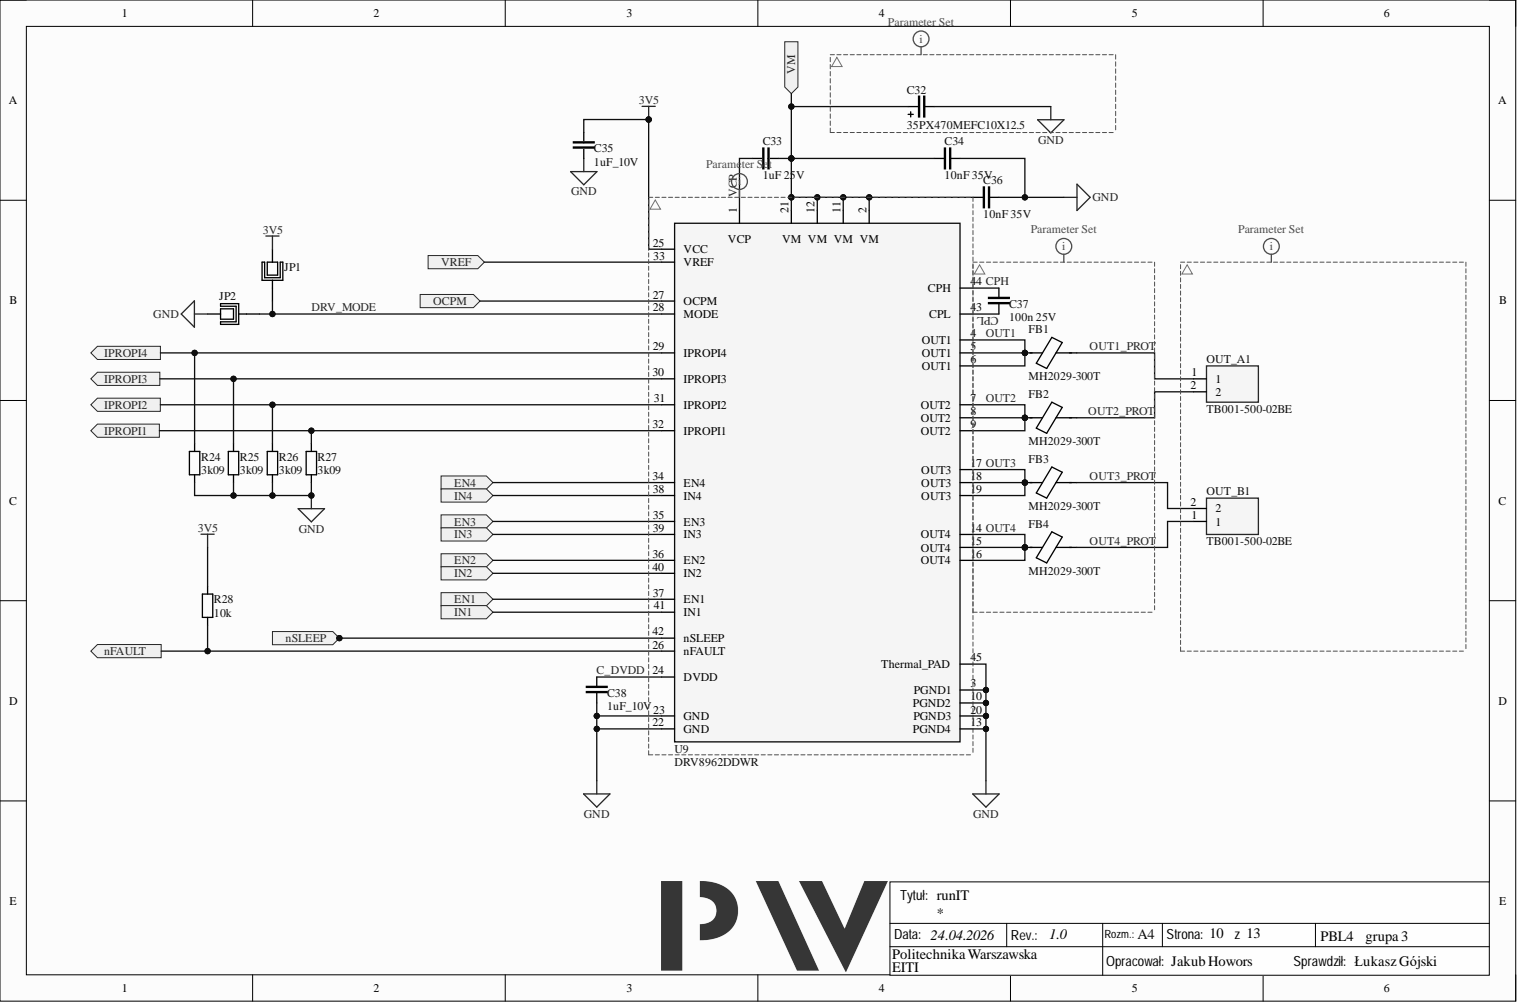
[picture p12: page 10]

9 | 3 0 0 T

1 5
1 6 | 3 0 0

1 0
2 0

2 3
2 2 | 1 3

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

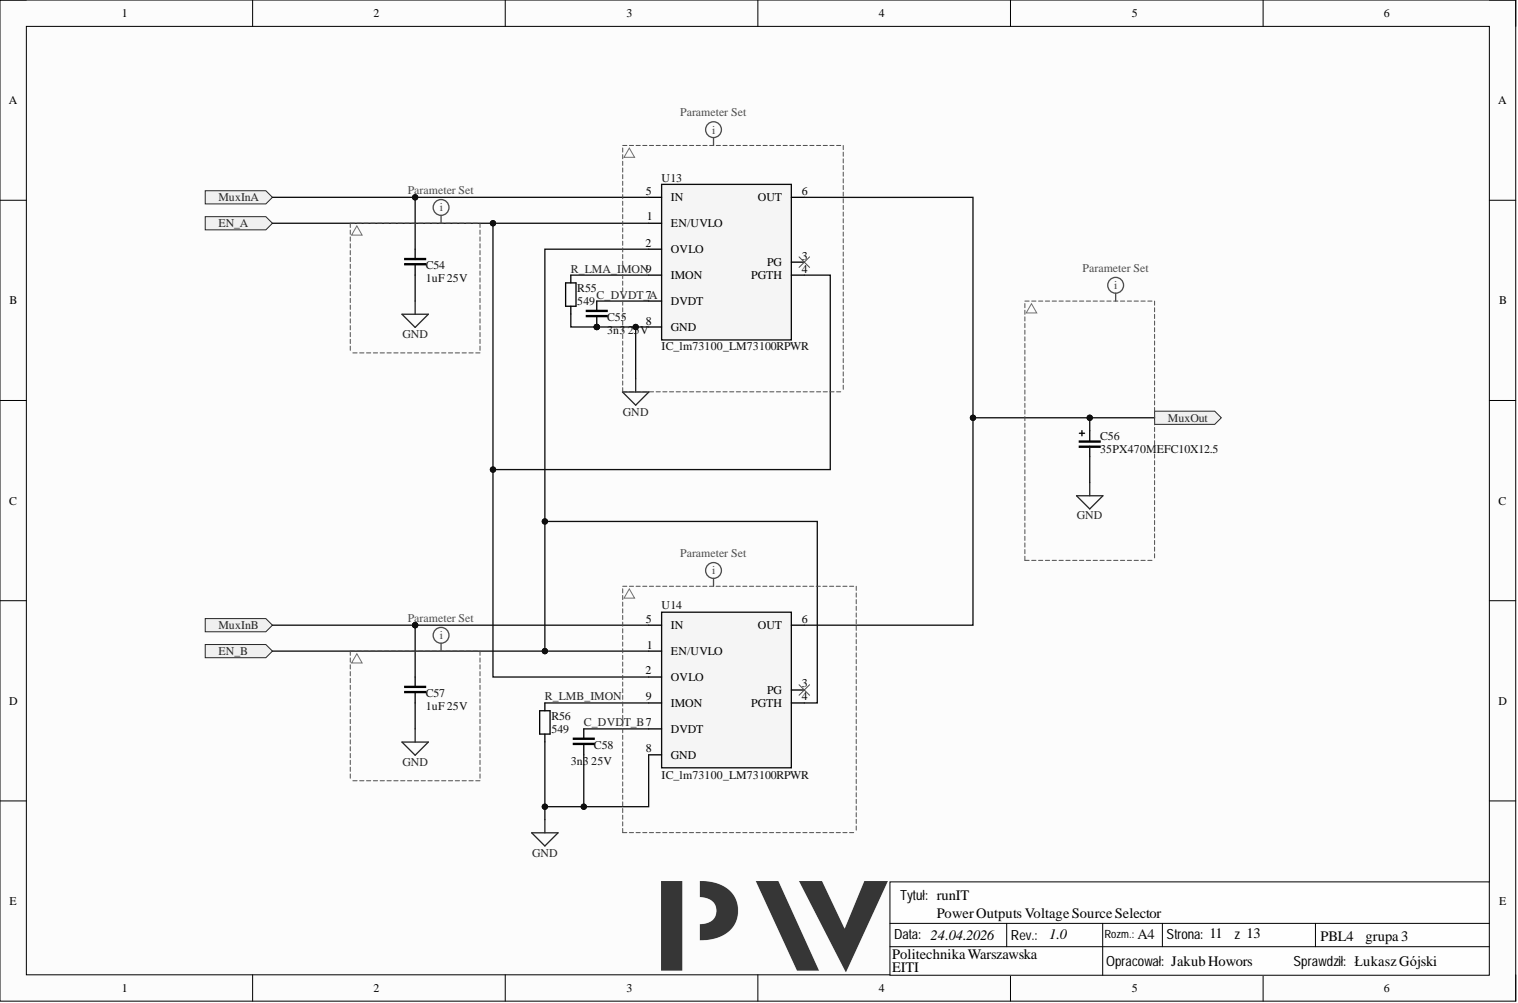
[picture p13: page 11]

R_ LMA _IMO | N | 9

Parameter Set

R_ LMB_IMO N | 9

T_B 7 | IMO N PG T H D V D T G N D

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

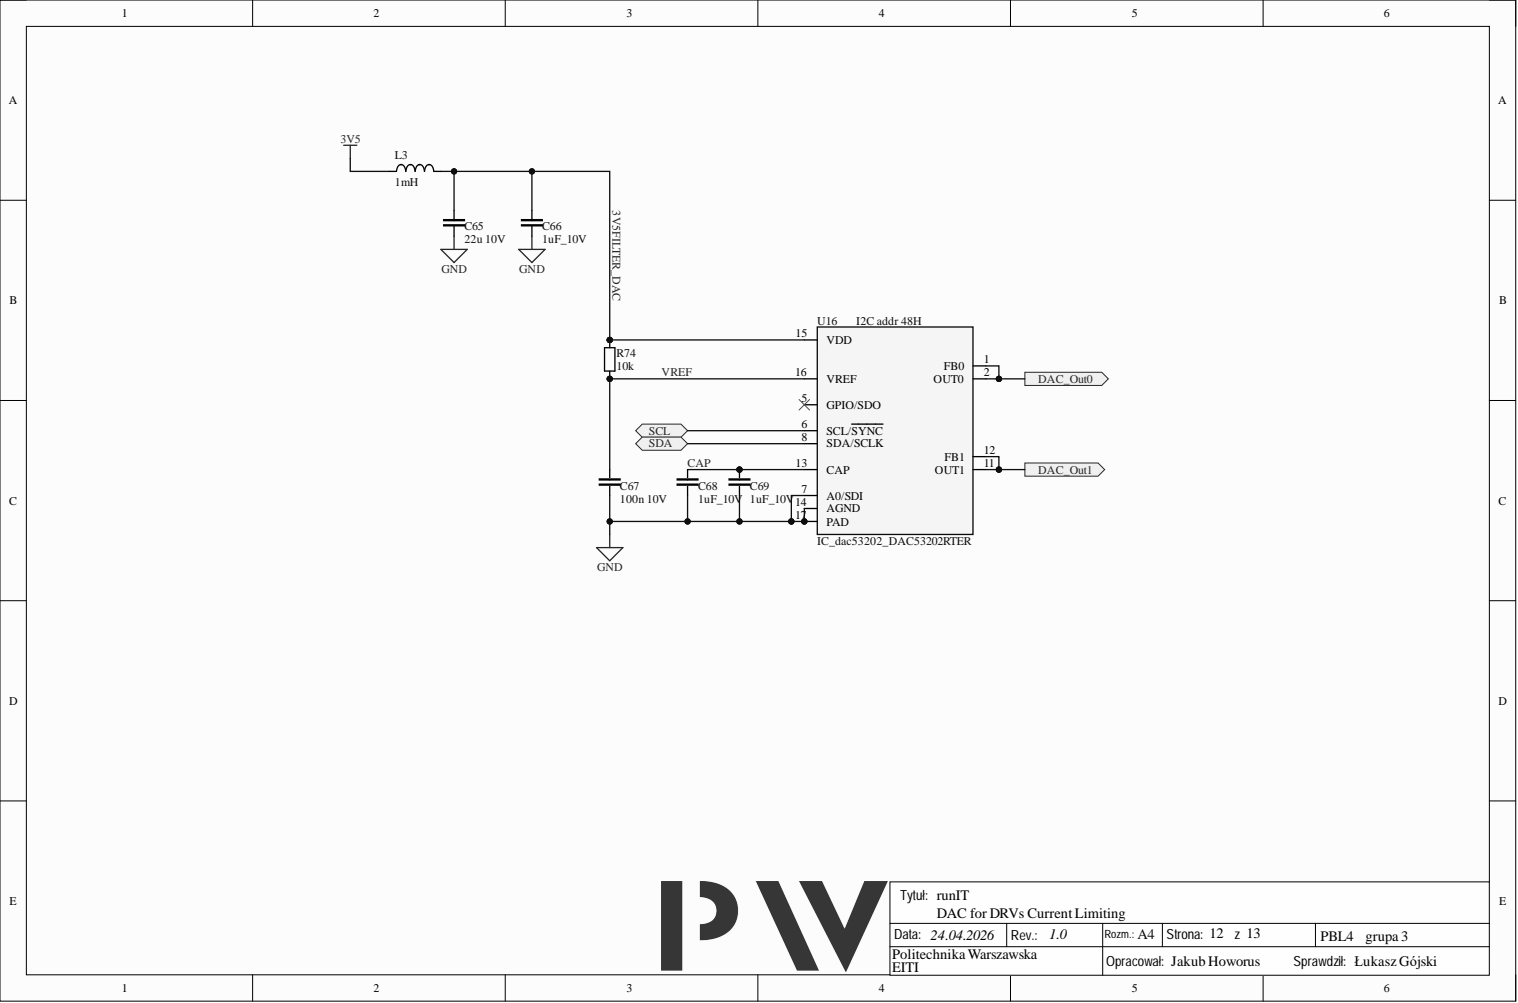
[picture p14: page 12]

Tytuł:
runIT
DAC for DRVs Current Limiting

Data: 24.04.2026 | Rev.: 1.0 | Rozm.: A4 | Strona: 12 z 13 | PBL4 grupa 3
Politechnika Warszawska EITI | | Opracował: Jakub Howorus Sprawdził: Łukasz Gójski

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


View from Top side (Scale 1:1)


View from Bottom side (Scale 1:1)







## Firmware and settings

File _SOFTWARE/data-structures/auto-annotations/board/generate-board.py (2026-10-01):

"""Generate the board catalog: the onboard devices, their fixed device IDs and wiring.

Source of truth:
- components/runit/runit_board_defs.h: `#define DEVICE_ID_<NAME> <id>  //@STATIC_DEVICE`,
  the I2C buses (`SYS_I2C_BUS_INTERNAL` / `SYS_I2C_BUS_USER`) and named board
  pins (`#define RUNIT_BOARD_<...> <pin>  // <label>`)
- components/runit/runit_board_cfg.c: `SYS_DEVICE_CREATE_ONBOARD(&g_<driver>_class, &(d_<driver>_cfg_t){.device_id = DEVICE_ID_<NAME>, ...})`,
  which names the driver; when data-structures/devices/device_<driver>.generated.json
  exists, the device links to that descriptor and takes its title. From the
  create call's config: `.i2c_bus`, `.i2c_addr` and every
  `SYS_IO_PIN_INIT(device, pin, mode)` (the pins the device takes). The
  `#if RUNIT_BOARD_DEV_<X>` bring-up switch around it says whether it is
  installed. `sys_io_set_mode` / `sys_io_set_level` calls in
  runit_board_devices_init are the board's own pin setup (status LEDs …).

The app names a device ID (in error payloads, events, pin references) from
this file, shows which pins onboard devices own, and puts user devices on the
user I2C bus.

Usage:
  python data-structures/auto-annotations/board/generate-board.py
"""
import json
import re
import sys
from pathlib import Path

try:
    import jsonschema
except ImportError:
    jsonschema = None

PROJECT_ROOT = Path(__file__).parents[3]
DEFS_PATH = PROJECT_ROOT / "components" / "runit" / "runit_board_defs.h"
CFG_PATH = PROJECT_ROOT / "components" / "runit" / "runit_board_cfg.c"
DEVICES_DIR = PROJECT_ROOT / "data-structures" / "devices"
OUT_PATH = PROJECT_ROOT / "data-structures" / "board" / "board.generated.json"
SCHEMA_PATH = PROJECT_ROOT / "data-structures" / "schema" / "board.schema.json"
SCHEMA_REL_PATH = SCHEMA_PATH.relative_to(PROJECT_ROOT).as_posix()

STATIC_DEVICE_RE = re.compile(r"^\s*#define\s+(?P<symbol>DEVICE_ID_(?P<name>\w+))\s+(?P<id>\d+)\s*//@STATIC_DEVICE\b", re.MULTILINE)
CREATE_RE = re.compile(r"SYS_DEVICE_CREATE_ONBOARD\(\s*&g_(?P<driver>\w+?)_class\s*,\s*&\(d_\w+?_cfg_t\)\s*\{\s*\.device_id\s*=\s*(?P<symbol>DEVICE_ID_\w+)")
SWITCH_RE = re.compile(r"^\s*#define\s+(?P<name>RUNIT_BOARD_DEV_\w+)\s+(?P<value>\d+)", re.MULTILINE)
BUS_RE = re.compile(r"^\s*#define\s+(?P<name>SYS_I2C_BUS_(?P<kind>INTERNAL|USER))\s+(?P<value>\d+)", re.MULTILINE)
BOARD_PIN_RE = re.compile(r"^\s*#define\s+(?P<name>RUNIT_BOARD_\w+)\s+(?P<value>\d+)\s*//\s*(?P<label>.*?)\s*$", re.MULTILINE)
FIELD_RE = re.compile(r"\.(?P<field>\w+)\s*=\s*(?P<value>\{[^{}]*\}|SYS_IO_PIN_INIT\([^()]*\)|SYS_IO_PIN_NONE_INIT|[\w]+)")
PIN_INIT_RE = re.compile(r"SYS_IO_PIN_INIT\(\s*(?P<device>\w+)\s*,\s*(?P<pin>\w+)\s*,\s*(?P<mode>\w+)\s*\)|SYS_IO_PIN_NONE_INIT")
LOOP_RE = re.compile(r"for\s*\(\s*uint8_t\s+(?P<var>\w+)\s*=\s*(?P<first>\w+)\s*;\s*(?P=var)\s*<=\s*(?P<last>\w+)\s*;\s*(?P=var)\+\+\s*\)\s*\{(?P<body>.*?)\n\s*\}", re.DOTALL)
PIN_CALL_RE = re.compile(r"sys_io_set_(?P<call>mode|level)\(\s*SYS_IO_PIN\(\s*(?P<device>\w+)\s*,\s*(?P<pin>\w+)\s*,\s*(?P<mode>\w+)\s*\)\s*(?:,\s*(?P<level>true|false)\s*)?\)")
ESP_PIN_RE = re.compile(r"^\s*#define\s+SYS_PIN_(?P<name>\w+)\s+(?P<pin>\d+)\s*(?://\s*(?P<note>.*?))?\s*$", re.MULTILINE)
COMMENT_RE = re.compile(r"/\*\s*(?P<text>.*?)\s*\*/", re.DOTALL)


def fail(message: str) -> None:
    raise SystemExit(f"ERROR: {message}")


def balanced(text: str, open_at: int) -> int:
    """Index just past the parenthesis that closes the one at open_at."""
    depth = 0
    for index in range(open_at, len(text)):
        if text[index] == "(":
            depth += 1
        elif text[index] == ")":
            depth -= 1
            if depth == 0:
                return index + 1
    fail(f"{CFG_PATH.name}: unbalanced parentheses after offset {open_at}")


def switch_at(cfg: str, position: int, switches: dict) -> bool:
    """Whether the `#if RUNIT_BOARD_DEV_<X>` block around position is on (outside any: yes)."""
    stack = []
    for match in re.finditer(r"^\s*#(?P<kind>if|ifdef|ifndef|endif)\b(?P<rest>.*)$", cfg[:position], re.MULTILINE):
        if match.group("kind") == "endif":
            if stack:
                stack.pop()
        else:
            stack.append(match.group("rest").strip())
    for condition in stack:
        name = condition.split()[0] if condition else ""
        if name in switches and not switches[name]:
            return False
    return True


def board_wiring(defs: str, cfg: str, device_ids: dict) -> tuple[dict, dict, list]:
    """Per device (symbol): installed, i2c, pins; plus the buses and the board's own pin setup."""
    switches = {match.group("name"): int(match.group("value")) != 0 for match in SWITCH_RE.finditer(cfg)}
    buses = {match.group("name"): int(match.group("value")) for match in BUS_RE.finditer(defs)}
    named_pins = {match.group("name"): (int(match.group("value")), match.group("label")) for match in BOARD_PIN_RE.finditer(defs)}

    def number(token: str, where: str) -> int:
        if re.fullmatch(r"0x[0-9a-fA-F]+|\d+", token):
            return int(token, 0)
        if token in named_pins:
            return named_pins[token][0]
        if token in buses:
            return buses[token]
        fail(f"{CFG_PATH.name}: {where}: can't resolve '{token}'")

    def device_id(token: str, where: str) -> int:
        if token not in device_ids:
            fail(f"{CFG_PATH.name}: {where}: '{token}' is not a //@STATIC_DEVICE")
        return device_ids[token]

    wiring = {}
    create_spans = []
    for match in CREATE_RE.finditer(cfg):
        start = cfg.index("(", match.start())
        end = balanced(cfg, start)
        create_spans.append((match.start(), end))
        body = cfg[match.end():end]
        symbol = match.group("symbol")
        entry = {"installed": switch_at(cfg, match.start(), switches)}
        pins = []
        for field in FIELD_RE.finditer(body):
            name, value = field.group("field"), field.group("value")
            if name == "i2c_bus":
                entry.setdefault("i2c", {})["bus"] = number(value, f"{symbol}.i2c_bus")
            elif name == "i2c_addr":
                entry.setdefault("i2c", {})["address"] = number(value, f"{symbol}.i2c_addr")
            elif "SYS_IO_PIN" in value:
                refs = list(PIN_INIT_RE.finditer(value))
                for index, ref in enumerate(refs):
                    if not ref.group("device"):
                        continue  # SYS_IO_PIN_NONE_INIT: not connected
                    pin = {"use": name if not value.startswith("{") else f"{name}[{index}]", "device": device_id(ref.group("device"), f"{symbol}.{name}"),
                           "pin": number(ref.group("pin"), f"{symbol}.{name}"), "mode": ref.group("mode")}
                    pins.append(pin)
        if pins:
            entry["pins"] = pins
        wiring[symbol] = entry

    # The board's own pin setup: sys_io_set_mode / sys_io_set_level outside the create calls.
    init = re.search(r"err_h\s+runit_board_devices_init\s*\(\s*void\s*\)\s*\{", cfg)
    setup = {}
    if init:
        body_start = init.end() - 1
        body_end = balanced(cfg.replace("{", "(").replace("}", ")"), body_start)
        calls = []
        for loop in LOOP_RE.finditer(cfg, body_start, body_end):
            first, last = number(loop.group("first"), "loop"), number(loop.group("last"), "loop")
            for value in range(first, last + 1):
                for call in PIN_CALL_RE.finditer(loop.group("body")):
                    calls.append((loop.start(), call, value if call.group("pin") == loop.group("var") else None))
        loop_spans = [(loop.start(), loop.end()) for loop in LOOP_RE.finditer(cfg, body_start, body_end)]
        for call in PIN_CALL_RE.finditer(cfg, body_start, body_end):
            if any(start <= call.start() < end for start, end in create_spans + loop_spans):
                continue
            calls.append((call.start(), call, None))
        for position, call, loop_pin in sorted(calls, key=lambda entry: entry[0]):
            device = device_id(call.group("device"), "pin setup")
            pin = loop_pin if loop_pin is not None else number(call.group("pin"), "pin setup")
            key = (device, pin)
            entry = setup.setdefault(key, {"device": device, "pin": pin, "mode": call.group("mode"), "installed": switch_at(cfg, position, switches)})
            if call.group("call") == "level":
                entry["level"] = call.group("level") == "true"
            # Label: the board pin define's comment, else the comment right above the call.
            label = next((text for name, (value, text) in named_pins.items() if value == pin and name.startswith("RUNIT_BOARD_TCA_") and device == device_ids.get("DEVICE_ID_TCA6424A")), None)
            if label is None:
                comments = [match for match in COMMENT_RE.finditer(cfg, body_start, position)]
                # A comment labels the calls under it, up to the next blank line.
                if comments and not re.search(r"\n\s*\n", cfg[comments[-1].end():position]):
                    label = " ".join(comments[-1].group("text").split()).rstrip(".")
            if label:
                entry.setdefault("label", label)
    i2c = {kind.lower(): value for kind, value in ((name.removeprefix("SYS_I2C_BUS_"), value) for name, value in buses.items())}
    # ESP pins the board uses outside sys_io (SYS_PIN_* in runit_board_defs.h, e.g. the I2C buses).
    gpio = device_ids.get("DEVICE_ID_GPIO_ESP")
    reserved = []
    for match in ESP_PIN_RE.finditer(defs):
        label = match.group("name").replace("_", " ")
        reserved.append({"device": gpio, "pin": int(match.group("pin")), "label": f"{label} ({match.group('note')})" if match.group("note") else label})
    return wiring, i2c, list(setup.values()), reserved


def build_document() -> dict:
    defs = DEFS_PATH.read_text(encoding="utf-8", errors="replace")
    cfg = CFG_PATH.read_text(encoding="utf-8", errors="replace")
    drivers = {match.group("symbol"): match.group("driver") for match in CREATE_RE.finditer(cfg)}
    device_ids = {match.group("symbol"): int(match.group("id")) for match in STATIC_DEVICE_RE.finditer(defs)}
    wiring, i2c, pin_setup, reserved = board_wiring(defs, cfg, device_ids)
    # Descriptor files don't always split the part number the way the driver does (device_ads_7128 vs d_ads7128).
    descriptors = {path.name.removesuffix(".generated.json").replace("_", ""): path for path in DEVICES_DIR.glob("device_*.generated.json")}
    devices = []
    for match in STATIC_DEVICE_RE.finditer(defs):
        symbol, device_id = match.group("symbol"), int(match.group("id"))
        driver = drivers.get(symbol)
        entry = {"id": device_id, "symbol": symbol, "name": match.group("name")}
        if driver:
            entry["driver"] = driver
            descriptor_path = descriptors.get(f"device{driver}".replace("_", ""))
            if descriptor_path:
                descriptor = json.loads(descriptor_path.read_text(encoding="utf-8"))
                entry["descriptor"] = descriptor["id"]
                entry["title"] = descriptor["title"]
        entry.update(wiring.get(symbol, {"installed": False}))
        devices.append(entry)
    if not devices:
        fail(f"{DEFS_PATH.name}: no //@STATIC_DEVICE defines")
    for key in ("id", "symbol"):
        values = [device[key] for device in devices]
        if len(values) != len(set(values)):
            fail(f"two static devices share a {key}: {values}")
    unknown = sorted(set(drivers) - {device["symbol"] for device in devices})
    if unknown:
        fail(f"{CFG_PATH.name} creates {unknown}, which have no //@STATIC_DEVICE define")
    return {
        "$schema": SCHEMA_REL_PATH,
        "schemaVersion": 1,
        "kind": "board",
        "source_files": [DEFS_PATH.relative_to(PROJECT_ROOT).as_posix(), CFG_PATH.relative_to(PROJECT_ROOT).as_posix()],
        "i2c_buses": i2c,
        "devices": sorted(devices, key=lambda device: device["id"]),
        "pin_setup": pin_setup,
        "reserved_pins": reserved,
    }


def validate(document: dict) -> None:
    if jsonschema is None:
        print("WARNING: jsonschema package not installed - skipping schema validation")
        return
    schema = json.loads(SCHEMA_PATH.read_text(encoding="utf-8"))
    errors = sorted(jsonschema.Draft202012Validator(schema).iter_errors(document), key=lambda error: list(error.path))
    if errors:
        details = "\n".join(f"  - at {'/'.join(map(str, error.path)) or '<root>'}: {error.message}" for error in errors)
        fail(f"board failed schema validation:\n{details}")


def main() -> int:
    document = build_document()
    validate(document)
    OUT_PATH.parent.mkdir(parents=True, exist_ok=True)
    OUT_PATH.write_text(json.dumps(document, indent=2) + "\n", encoding="utf-8")
    print(f"Wrote {OUT_PATH.relative_to(PROJECT_ROOT)} ({len(document['devices'])} static devices)")
    return 0


if __name__ == "__main__":
    sys.exit(main())

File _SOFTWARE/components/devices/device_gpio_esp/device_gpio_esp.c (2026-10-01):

#include <stdint.h>
#include <stdlib.h>
#include <string.h>
#include "device_gpio_esp.h"
#include "driver/gpio.h"
#include "esp_adc/adc_cali.h"
#include "esp_adc/adc_cali_scheme.h"
#include "esp_adc/adc_continuous.h"
#include "esp_adc_config.h"
#include "esp_pwm.h"
#include "esp_timer.h"
#include "freertos/FreeRTOS.h"
#include "freertos/queue.h"
#include "freertos/task.h"
#include "shared_io_types.h"
#include "sys_device.h"
#include "sys_error.h"
#include "sys_error_codes.h"
#include "sys_error_io.h"
#include "sys_io.h"
#include "utils.h"

#define OWNER OWNER_DEVICE

static const uint64_t pin_bitmask = SOC_GPIO_VALID_GPIO_MASK;

#define CONFIG_ESP_GPIO_DEBOUNCE_TIME_US 50000

esp_pin_obj_t pin_pool[GPIO_NUM_MAX] = {0};
uint64_t configured_pins = 0;
uint8_t gpio_esp_device_id = 0;  // for the ISR and the ADC task, which have no handle
R_MUTEX_DEFINE(gpio_mutex);

// GPIO mode -> ESP-IDF gpio_config_t fields. GPIO_MODE_DISABLE (0) marks a
// mode this table doesn't support, so validity is a single lookup.
static const struct {
  gpio_mode_t mode;
  gpio_pullup_t pull_up;
  gpio_pulldown_t pull_down;
} k_gpio_mode_map[] = {
    [SYS_IO_MODE_INPUT] = {GPIO_MODE_INPUT, GPIO_PULLUP_DISABLE, GPIO_PULLDOWN_DISABLE},
    [SYS_IO_MODE_INPUT_PULLUP] = {GPIO_MODE_INPUT, GPIO_PULLUP_ENABLE, GPIO_PULLDOWN_DISABLE},
    [SYS_IO_MODE_INPUT_PULLDOWN] = {GPIO_MODE_INPUT, GPIO_PULLUP_DISABLE, GPIO_PULLDOWN_ENABLE},
    [SYS_IO_MODE_OUTPUT_PUSH_PULL] = {GPIO_MODE_INPUT_OUTPUT, GPIO_PULLUP_DISABLE, GPIO_PULLDOWN_DISABLE},
    [SYS_IO_MODE_OUTPUT_OPEN_DRAIN] = {GPIO_MODE_INPUT_OUTPUT_OD, GPIO_PULLUP_DISABLE, GPIO_PULLDOWN_DISABLE},
};

// sys_io interrupt mode -> ESP-IDF interrupt type. GPIO_INTR_DISABLE (0)
// marks a mode this table doesn't support.
static const gpio_int_type_t k_gpio_intr_map[] = {
    [SYS_IO_INTR_MODE_RISING_EDGE] = GPIO_INTR_POSEDGE,
    [SYS_IO_INTR_MODE_FALLING_EDGE] = GPIO_INTR_NEGEDGE,
    [SYS_IO_INTR_MODE_BOTH_EDGES] = GPIO_INTR_ANYEDGE,
};

// Pin ISR: publishes the edge; sys_event defers delivery to its task.
static void IRAM_ATTR _gpio_pin_isr_trampoline(void* arg) {
  esp_pin_obj_t* pin = (esp_pin_obj_t*)arg;
  if (!pin) return;

  // Only switches are debounced. A chip alert line (debounce off) holds a
  // latched flag: an edge dropped here would never be followed by another,
  // so the flag would stay set and the line stuck asserted.
  if (pin->intr_config.debounce) {
    uint64_t current_time = esp_timer_get_time();
    if ((current_time - pin->last_isr_time) < CONFIG_ESP_GPIO_DEBOUNCE_TIME_US) {
      return;
    }
    pin->last_isr_time = current_time;
  }

  int level = gpio_get_level((gpio_num_t)pin->io_num);
  sys_io_intr_mode_e edge = level ? SYS_IO_INTR_MODE_RISING_EDGE : SYS_IO_INTR_MODE_FALLING_EDGE;
  SE_release(sys_io_publish(gpio_esp_device_id, pin->io_num, edge, level, 0));
}

// --- VTABLE Implementations (IO Contract) ---

static SE_MUST_USE err_h contract_io_gpio_esp_reset_pin(void* handle, sys_io_pin_num_t pin) {
  SYS_DEV_CTX_FROM(gpio_ctx_t, c, handle);
  VERIFY_PIN(SYS_DEV_GET_ID(c), pin, pin_bitmask);

  bool was_adc = false;
  adc_cali_handle_t cali_handle = NULL;
  bool was_configured = false;
  esp_err_t pwm_err = ESP_OK;

  if (R_MUTEX_LOCK(gpio_mutex, portMAX_DELAY) == pdTRUE) {
    esp_pin_obj_t* pin_obj = pin_obj_get(pin);
    if (pin_obj != NULL) {
      was_configured = true;
      was_adc = (pin_obj->pin_mode == SYS_IO_MODE_ADC);
      cali_handle = pin_obj->hw.adc_cfg.cali_handle;
      // Under the lock: the channel and timer pools are shared by every PWM pin.
      if (pin_obj->pin_mode == SYS_IO_MODE_PWM) pwm_err = esp_pwm_release(pin_obj);
      configured_pins &= ~(1ULL << pin);
      memset(pin_obj, 0, sizeof(*pin_obj));
    }
    R_MUTEX_UNLOCK(gpio_mutex);
  }

  if (!was_configured) return NULL;

  // Every step runs even if an earlier one fails; the first failure is returned.
  err_h err = NULL;
  SYS_DEV_TEARDOWN_STEP(err, SE_CONVERT_ESP(pwm_err));
  SYS_DEV_TEARDOWN_STEP(err, SE_CONVERT_ESP(gpio_reset_pin((gpio_num_t)pin)));
  SYS_DEV_TEARDOWN_STEP(err, SE_CONVERT_ESP(gpio_isr_handler_remove((gpio_num_t)pin)));
  SYS_DEV_TEARDOWN_STEP(err, SE_CONVERT_ESP(gpio_set_intr_type((gpio_num_t)pin, GPIO_INTR_DISABLE)));

  if (was_adc) {
    if (cali_handle != NULL) {
      SYS_DEV_TEARDOWN_STEP(err, SE_CONVERT_ESP(adc_cali_delete_scheme_curve_fitting(cali_handle)));
    }
    SYS_DEV_TEARDOWN_STEP(err, SE_CONVERT_ESP(esp_adc_update_active_channels()));
  }

  return err;
}
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

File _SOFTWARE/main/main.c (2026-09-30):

#include <esp_log.h>
#include <freertos/FreeRTOS.h>
#include <freertos/task.h>
#include "runit.h"

#define TAG __FILE_NAME__

void app_main(void) {
  err_h err = runit_start();
  if (err != NULL) {
    ESP_LOGE(TAG, "runIT startup failed; system halted in safe state");
    SE_release(err);
  }
  while (1) {
    vTaskDelay(portMAX_DELAY);
  }
}

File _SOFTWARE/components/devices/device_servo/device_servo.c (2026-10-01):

#include <stdlib.h>
#include "device_servo.h"
#include "sys_device.h"
#include "sys_error.h"

#define OWNER OWNER_DEVICE

#define SERVO_FREQUENCY_HZ 50
#define SERVO_PERIOD_US 20000
#define SERVO_DUTY_TICKS 4096  /* 12-bit duty of the IO contract (PCA9685, LEDC) */
#define SERVO_MAX_OFFSET_US 500

enum { SERVO_STEP_PWM = 0 };

typedef struct servo_ctx_t {
  sys_device_base_t base;  // must be first
  d_servo_cfg_t cfg;
  sys_io_pin_ref_t pwm_pin;  // cfg.pwm_pin, converted once at install
  int16_t offset_us;
  uint16_t pulse_us;  // pulse last sent, 0 = pin not driven
} servo_ctx_t;

// The one place that talks to the pin: clamps to the configured range and converts to duty.
static SE_MUST_USE err_h servo_send(servo_ctx_t* c, int32_t pulse_us) {
  if (pulse_us < c->cfg.min_us) pulse_us = c->cfg.min_us;
  if (pulse_us > c->cfg.max_us) pulse_us = c->cfg.max_us;
  SE_TRY(sys_io_set_pwm_duty(c->pwm_pin, (uint32_t)pulse_us * SERVO_DUTY_TICKS / SERVO_PERIOD_US));
  c->pulse_us = (uint16_t)pulse_us;
  return NULL;
}

static SE_MUST_USE err_h servo_stop(servo_ctx_t* c) {
  SE_TRY(sys_io_set_pwm_duty(c->pwm_pin, 0));
  c->pulse_us = 0;
  return NULL;
}

/* ---- Operations ---- */

static SE_MUST_USE err_h op_home(void* handle, const uint8_t* args, size_t len, sys_device_reply_t* reply) {
  (void)args, (void)len, (void)reply;
  SYS_DEV_CTX_FROM(servo_ctx_t, c, handle);
  return servo_send(c, (int32_t)c->cfg.home_us + c->offset_us);
}

static SE_MUST_USE err_h op_set_offset(void* handle, const uint8_t* args, size_t len, sys_device_reply_t* reply) {
  (void)len, (void)reply;
  SYS_DEV_CTX_FROM(servo_ctx_t, c, handle);
  SYS_DEVICE_OP_ARGS(servo_set_offset_t, a, args);
  SE_CHECK_IN_RANGE((int)a.offset_us, -SERVO_MAX_OFFSET_US, SERVO_MAX_OFFSET_US);
  c->offset_us = a.offset_us;  // takes effect with the next move, the servo stays where it is
  return NULL;
}

static SE_MUST_USE err_h op_set_angle(void* handle, const uint8_t* args, size_t len, sys_device_reply_t* reply) {
  (void)len, (void)reply;
  SYS_DEV_CTX_FROM(servo_ctx_t, c, handle);
  SYS_DEVICE_OP_ARGS(servo_set_angle_t, a, args);
  SE_CHECK_IN_RANGE((uint32_t)a.angle_deg, 0, 180);
  int32_t span = (int32_t)c->cfg.max_us - c->cfg.min_us;
  return servo_send(c, c->cfg.min_us + span * a.angle_deg / 180 + c->offset_us);
}

static SE_MUST_USE err_h op_get_pulse(void* handle, const uint8_t* args, size_t len, sys_device_reply_t* reply) {
  (void)args, (void)len;
  SYS_DEV_CTX_FROM(servo_ctx_t, c, handle);
  return sys_device_reply_put(reply, &c->pulse_us, sizeof(c->pulse_us));
}

// The whole interface of the device on one screen.
static const sys_device_op_t s_ops[] = {
    SYS_DEVICE_OP(SERVO_OP_HOME, servo_no_args_t, op_home),
    SYS_DEVICE_OP(SERVO_OP_SET_OFFSET, servo_set_offset_t, op_set_offset),
    SYS_DEVICE_OP(SERVO_OP_SET_ANGLE, servo_set_angle_t, op_set_angle),
    SYS_DEVICE_OP_RO(SERVO_OP_GET_PULSE, servo_no_args_t, op_get_pulse),
};

/* ---- Lifecycle ---- */

// Doubles as the install rollback path: no step may early-return.
static SE_MUST_USE err_h device_uninstall(void* handle) {
  SYS_DEV_CTX_FROM(servo_ctx_t, c, handle);
  err_h err = NULL;
  IF_SYS_DEV_STEP_DONE(c, SERVO_STEP_PWM) {
    SYS_DEV_TEARDOWN_STEP(err, servo_stop(c));
  }
  free(c);
  return err;
}

static SE_MUST_USE err_h device_reset(void* handle) {
  SYS_DEV_CTX_FROM(servo_ctx_t, c, handle);
  c->offset_us = 0;
  return servo_stop(c);
}

// Fault safe state: no pulse, the servo goes limp.
static SE_MUST_USE err_h device_suspend(void* handle) {
  SYS_DEV_CTX_FROM(servo_ctx_t, c, handle);
  uint16_t last = c->pulse_us;
  SE_TRY(servo_stop(c));
  c->pulse_us = last;  // remembered for resume
  return NULL;
}

static SE_MUST_USE err_h device_resume(void* handle) {
  SYS_DEV_CTX_FROM(servo_ctx_t, c, handle);
  return c->pulse_us ? servo_send(c, c->pulse_us) : NULL;
}

static SE_MUST_USE err_h device_install(const void* cfg_blob, void** out_device_handle) {
  const d_servo_cfg_t* cfg = (const d_servo_cfg_t*)cfg_blob;

  SE_CHECK_IN_RANGE((uint32_t)cfg->max_us, 1, SERVO_PERIOD_US);
  SE_CHECK_IN_RANGE((uint32_t)cfg->min_us, 0, cfg->max_us);
  SE_CHECK_IN_RANGE((uint32_t)cfg->home_us, cfg->min_us, cfg->max_us);

  servo_ctx_t* c = (servo_ctx_t*)calloc(1, sizeof(servo_ctx_t));
  SE_CHECK_IF_ALLOCATED(c);
  c->cfg = *cfg;
  c->base.device_id = cfg->device_id;
  err_h err = NULL;

  c->pwm_pin = c->cfg.pwm_pin;
  SYS_DEV_INSTALL_STEP_BIT(c, SERVO_STEP_PWM, sys_io_set_pwm_frequency(c->pwm_pin, SERVO_FREQUENCY_HZ), "pwm frequency");

  *out_device_handle = c;
  return NULL;

fail:
  SYS_DEV_INSTALL_FAIL(err, out_device_handle, device_uninstall, c);
  return NULL;
}

static const uint8_t s_pin_refs[] = {offsetof(d_servo_cfg_t, pwm_pin)};

// No contract: only the lifecycle and the operations above.
const sys_device_class_t g_servo_class = {
    .type_id = SERVO_TYPE_ID,
    .cfg_size = sizeof(d_servo_cfg_t),
    SYS_DEVICE_PINS(s_pin_refs),
    .name = "SERVO",
    .ops = {.install = device_install,
        .uninstall = device_uninstall,
        .reset = device_reset,
        .suspend = device_suspend,
        .resume = device_resume},
    SYS_DEVICE_OPS(s_ops),
};

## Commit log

2026-02-22 Fixed aliases display in publish also a little bit of vibecoded alignment in formating
    [test_dump.txt]
2026-04-29 first save
    [test_dump.txt]
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2026-05-02 Added working dev cfg dispatcher, test on pca, in driver only print
2026-05-03 some fixes, and status edits
    [main.c]
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2026-05-12 PCB files added
    [ADCHighVoltageInputsSchDoc.SchDoc, Bill of Materials-PCB.xlsx, Common.SchLib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]
2026-05-12 Update repo , readme
    [Bill of Materials-PCB.xlsx, PBL4_2026L_runIT.xlsx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]
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2026-06-08 error handling cleanup on esp_gpios and packet parse
    [config_io.c, esp_adc_config.c]
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2026-06-14 usunięcie zbędnych folderów
    [ADCHighVoltageInputsSchDoc.SchDoc, Bill of Materials-PCB.xlsx, Common.SchLib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]
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2026-07-13 move into "device concept" and contract based registration using device_id, run it kernel now is sys_xx , ble cchars are now fullly dynamic, error handling partialy inside devices adapeters(old provi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
    [config_io.c, esp_adc_config.c]
2026-07-20 Partial rework of callbacks in devices
    [esp_adc_config.c, sys_i2c.c]
2026-07-25 errors mostly reowrkedalong driver install
    [esp_adc_config.c]
2026-08-01 prepration for vm development save before error logging update
    [esp_adc_config.c]
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2026-09-17 error severity with handle base, device importance as error handling setting per device
2026-09-19 chore: prepare vm_ui branch, clean test hooks and files, configure board devices
2026-09-19 fix(runit): fix telemetry sender return, remove sample hook stub and dead test decl
2026-09-21 hbridge sys contract + device_dvr8962 + servo fature + hbridge feature skeleton
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2026-09-22 auto-generated json from annotations (device) app component ble. data stream and packetPacker.
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2026-09-27 app uid - devices, settings, objects
    [partitions.csv]
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2026-09-30 restore of _HARDWARE
    [ADCHighVoltageInputsSchDoc.SchDoc, Bill of Materials-PCB.xlsx, Common.SchLib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]
2026-09-30 flatten of device structure, removed decoders, custom operations per device without contracts. Test only on pca - rest is migration
2026-10-01 Device simplification done:- migration of all devices not tested yet
    [device_servo.generated.json]
2026-10-01 architectural trials to auto generate devices
    [device_pca9685.pins.csv]
2026-10-01 app 33772s sefl kill fix + tca not responding at reset fix
    [device_ap33772s.c, device_gpio_esp.c, device_tca6424a.c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]
2026-10-10 Firmware sys-v2: new component tree on contracts, old code moved to legacy/
    New firmware tree, grouped by layer:
    - components/core: utils, errors, cmd (handler type, cmd_reply, ERR_CMD_*),
    router
    - components/sys: sys_device (type registry + generic CREATE/REMOVE/INFO/OPS,
    declared dependencies), sys_io (IO + PINS contracts), sys_power (POWER_MONITOR
    incl. GET_POWER, POWER_VREG), sys_event, sys_actions, sys_connector, sys_i2c,
    sys_ble, sys_uart
    - components/devices: GPIO ESP (with pin and ADC-threshold interrupts), PCA9685,
    TPS55289 (asynchronous soft rise)
    Device layer: devices and contracts depend on cmd, not on the router; device
    types register themselves (SYS_DEVICE_TYPE_DEFIN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
2026-10-10 Simplify core and the routers: shared cmd helpers, one route lookup
    - router_route is router_call over the root table (no second lookup loop,
    root_entry_t removed); ROUTER_OP_DATA (no user) and the ignored
    router_link_lost argument removed.
    - err_pool: the free-count / min-free statistics nobody read are gone.
    - cmd_append and cmd_name_arg replace two identical copies of put() and three
    ways of checking a NUL-terminated name. The connector and BLE CHAR_CREATE
    names are now strict like the actions ones (nothing after the NUL).
2026-10-10 Simplify sys_uart and sys_actions: one send, one id check
    - sys_uart: link and connector provider share one uart_send (the router link's
    peer and the provider's endpoint are the same single UART address).
    - sys_actions: check_id() replaces the same ERR_CHECK written five times.
2026-10-10 Simplify the device layer: dependencies in the base struct, shared PINS ops
    - sys_device: the declared dependencies live in sys_device_base_t
    (sys_device_use(&c->base, dep)), so the hidden global of the device under
    construction and the "only from create()" check are gone; dead
    sys_device_u16 removed; the header comment no longer repeats SYS_DEVICE.MD.
    - SYS_PINS_STATE_HANDLERS / SYS_PINS_STATE_ENTRIES write the four state-only
    PINS ops once (identical in PCA9685 and GPIO ESP).
    - TPS55289: tps_set_enable(false) goes through tps_rail_off, the soft-rise
    limit is a constant, the reference is written with sys_i2c_reg_write_u16.
    - GPIO ESP: pin_in_mode and drive replace the repeated mod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
2026-10-18 app frame, Project/Devices/Code screens, Electron; error texts per module, error log kept for the app
    - runit-app: the app's frame and UI kit (src/ui, design/), Project screen,
    Devices view, Code view variables, settings and console (src/app),
    Electron desktop app (electron/, electron-builder.yml); backend errors
    read for a user, error log, safe state, events; browser and hardware tests
    - errors: messages split into errors_<module>.json (error-texts schema),
    generate_errors.py and errors.schema.json follow
    - sys_log: latest error records kept in RAM for the app (SYS_LOG_ERRORS_KEPT)
    - descriptors: contracts and devices extended, manuals and sources published
    in generated/; power ma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
2026-10-19 app: safe state, power live view, run/debug panel, canvas scopes; firmware and docs in step
2026-10-19 restructure: firmware to runit-esp/, descriptors to runit-app/generated/, app in the graph
    _SOFTWARE now holds two projects side by side: runit-esp/ (ESP-IDF project:
    components, main, CMakeLists, sdkconfig, partitions) and runit-app/. The
    published descriptors moved to runit-app/generated/; templates/, tools/ and
    .claude/ stay shared. Generators, schema paths, app configs and tests, skill
    scripts, docs and the graphify scripts follow. The graph now covers the app's
    TypeScript and its docs. The stale top-level devices/ folder is removed.
2026-10-19 router: sys_system takes the sys key, safe state and dead-man; one client per link
    - sys/sys_system: the sys ops (ROUTER_KEY_SYS), the safe state and the
    dead-man, moved out of the router; runit registers it like every module
    router and wires the BLE disconnect to sys_system_link_lost
    - router: the watch (frame, urgent) instead of safe state and dead-man;
    no peer (error record header is [link][seq][flags][req_len]), one
    thread-local route, links registered at boot without a lock, the
    internal link without a stub send, answer reports its own error
    - sys_safe_reason_e / SYS_SAFE_*, SYS_SYSTEM_OP_RESTART,
    CONFIG_SYS_SYSTEM_DEADMAN_DEFAULT_MS; app decoder, tests and docs in step
    - de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
2026-10-19 devkit option: the firmware for a plain ESP32-S3 devkit and the app for it
    - runit: CONFIG_RUNIT_BOARD (PCB / devkit / no devices) replaces
    RUNIT_ONBOARD_DEVICES; a devkit gets only the ESP GPIO as device 0 and a
    power layout with no rails, monitor or sink (USB limits);
    sdkconfig.devkit.defaults builds it (4 MB flash)
    - board_devkit.json published next to board.json; the board schema no
    longer requires power sources or an input monitor
    - app: one code base, the board descriptor chosen at start
    (VITE_RUNIT_BOARD, .env.devkit): npm run dev:devkit (port 5181),
    npm run app:devkit; the window title says devkit
    - runit.code-workspace: the repo and runit-esp as its own folder, so the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
2026-10-19 how-to-runit: running on a devkit, the PCB, dynamic devices or an own board
2026-10-19 errors: the error record and its command type; a tag's severity only
    - err_record (err_wire.c) replaces router_err_record: errors owns the
    record (ERROR answer, errors stream, history); err_cmd_t replaces
    router_cmd_t and types the sink (no void* origin); ERR_RECORD_* and
    err_record_src_e published; CONFIG_ERRORS_RECORD_REQ_MAX
    - the chain encoder merged into err_record
    - a node has no severity of its own: the sev field, ERR_SEV_DEFAULT, the
    _SEV, _RAW and ERR_TRY_WRAP macros removed; err_chain_sev is the
    highest of the chain; the record's nodes are [tag][len][payload], the
    app takes a node's severity from errors.json
    - err_tag_info, err_module, err_log_ctx internal (err_internal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
2026-10-19 sys_device: ERR_KEEP_FIRST in errors, the router header read with memcpy, collapsed macros restored
    - SYS_DEVICE_KEEP_FIRST moves to errors as ERR_KEEP_FIRST (used by drivers, sys_pins, sys_power_manager)
    - u16_at copies go: memcpy on the little-endian target, a packed [id][op] header in the router
    - SYS_DEVICE_HANDLER and ERR_SYS_IO_MAP are multi-line macros again
    - SYS_DEVICE_TYPE_DEFINE usage and SYS_DEVICE_NEW.md list .suspend / .resume
    - err_modules.h in order with 12 reserved; ERRORS.MD points to it instead of repeating the list
2026-10-19 sys_connector: the connector holds its info struct, one locked snapshot; gpio_esp ADC and PWM state grouped
2026-10-19 runit-flow: the firmware flow page (links, router, modules, devices, VM, streams), linked from how-to-runit
2026-10-19 sys_i2c: state in one struct, SYS_I2C_OP_* and clearer local macro names, raw access always in (Open: a Kconfig switch); #define values aligned in a column; .clang-format off (code formatted by hand)
2026-10-19 sys_power: sys_device_read (a fixed-size answer, ERR_CMD_BAD_LEN otherwise) for the getters of sys_power, sys_io, sys_pins and sys_hbridge; LIST_OPTIONS checks whole options; the four power contracts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
2026-10-19 sys_power_manager: state in one struct (s_cfg alone: read before init), starved a field, battery thresholds through one helper, USB current from highest_offer, tables and enums in columns
2026-10-19 sys_power_manager: the board config holds the layout (rails, monitors, source pins, sink), the user's choices are remote: SET_CONFIG {enabled, strict, margin, source without pins}, SET_PD / GET_PD (h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
2026-10-19 commands mirror: app follows the direction byte (read / write sides)
    The backend builds every service and device call with its side (cmd_dir_e) after the key; the args are a struct, or rows for an array side. A setting is one command with a read and a write, read without a key. Settings, the devices' operations, the power and console screens, the test fixtures and the hardware tests follow. Generated contract_device / contract_sys refreshed.
2026-10-20 sys_project: state in one struct (s_project), frames built by put_frame, the parser without a header buffer, OPTIONS read through sys_project_autostart, tables in columns
2026-10-20 sys_project: ERASE removes the devices the project created (REMOVE sweep, the board's stay); the app stops the VM and erases before every save
2026-10-20 sys_project: the boot option in NVS (nothing / load / run), done at a boot and right after a save; the start section (EXEC) apart from the program, RUN runs it, the new LOAD leaves it out; the app sa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
2026-10-20 tests: the python suites on the direction byte (router_link.frame from the descriptors; router_tests, board_tests, vm_suite on the merged commands); ble_suite, ble_link and vm_core_tests removed (BLE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
2026-10-20 board and app: DRV8962 with one current limit, sys_power / sys_device / sys_hbridge / sys_io contracts and descriptors, the power manager board config, schemas and crosscheck; app: devices, power and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
2026-10-20 docs: the direction byte, read / write sides and merged commands across the firmware, skills, templates and app docs; frame overhead of a VM command is 5 B; comments and schema examples on the merged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
2026-10-21 device_tca6424a: the RST pin taken unconditionally, the reset pause only when it is wired
2026-10-21 sys_device: the error map in sys_device_errors.h, the error module and the policies by device ID in sys_device_errors.c; the registry's table mux removed
2026-10-21 error policy: built-in responses on the failing device (suspend, reset), chosen in the device's policy card
2026-10-21 board_time: one clock for the board in core/time; the event's t_ms is the board's clock (u64), like the error record's stamp
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2026-10-21 device contracts: one set of shared macros (SYS_DEVICE_CONTRACT_DECLARE, OP_READ / OP_WRITE / OP_ENTRY*) in place of each contract's own
2026-10-21 sys_device: the registry's ops written like a driver's (OP_READ / OP_WRITE, a sys_device_op_t table)
2026-10-21 sys_device: the registry refuses a suspended device's writes (OP_ENTRY_W_ALWAYS for the exceptions); SYS_DEVICE_TYPE_DEFINE(NAME, cfg_t, ctx_t, table)
2026-10-21 suspended devices: every write refused, every read answered; ALWAYS only for the firmware's plumbing
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2026-10-21 esp32s3_gpio: one pin table behind a private API, ADC rebuilt under its mutex (no handshake), err_h in PWM / ADC, configure_pin split
2026-10-21 esp32s3_gpio: pins a native peripheral reserved in ESP-IDF (flash, PSRAM, I2C, SPI, USB-Serial-JTAG) are locked; SET_MODE refuses them
2026-10-21 sys_event: subscribe_device (inline) / subscribe_fn (event task), publish_deferred; flags carry only NOTIFY; device events declared next to their table
2026-10-21 drv8962: pins through sys_pins_owned_t (sys_pins_take for IO-written pins), apply_limit / latch_overcurrent / on_nfault split out; sys_pins tolerates a device without MODE/RESET
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2026-10-22 app Code view canvas and devices, backend catalog/errors, map block, servo and connector updates, regenerated descriptors, docs and tests
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2026-10-26 sys_connector: a connector is its byte (connector, provider, endpoint)
    - One number per stream: the connector byte names it and starts every frame it sends.
    No connector ID, no name; the API, commands (CREATE/REMOVE/BIND/UNBIND/SUSPEND/RESUME/INFO)
    and errors take `connector`; INFO per entry {connector, flags, n, bindings}.
    - System connectors SYS_CONNECTOR_LOGS/_ERRORS/_TELEMETRY/_EVENTS (0x03/0x04/0x02/0x06) and
    transport_e in config/sys_connector_config.h (group `connector` in enums.json); MQTT (3) kept
    unpublished until it has a provider.
    - Registry: a packed array + count (no conn_t wrapper); ERR_CONN_FULL (code 11), code 1 unused;
    sys_connector_list / sys_connector_exists / s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
2026-10-26 router links are the connectors' providers; sys_connector API trimmed
    - A transport registers once: router_link_t {send(endpoint, frame, len, answer), max_frame(endpoint),
    answer_endpoint}; the router answers to answer_endpoint, the connectors stream through the same link
    (router_link_get). sys_connector_provider_t, sys_connector_register_provider, providers[] and
    CONFIG_SYS_CONNECTOR_PROVIDERS_MAX are gone; UART and BLE have one link each (BLE: answers wait
    100 ms, stream frames 20 ms).
    - sys_log_init() takes no connector: logs go to SYS_CONNECTOR_LOGS like errors to _ERRORS;
    sys_connector_exists is gone.
    - sys_connector.h keeps init, bind, send, max_payload, is_task; what only th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
2026-10-27 sys_connector is sys_data_connector
    - The component, its files, API (sys_data_connector_*), system connectors (SYS_DATA_CONNECTOR_*),
    Kconfig (CONFIG_SYS_DATA_CONNECTOR_*), error module (ERR_MOD_SYS_DATA_CONNECTOR, same number) renamed;
    ERR_CONN_*, ROUTER_KEY_CONN and the wire format unchanged.
    - err_modules.h and the error map realigned; descriptors regenerated (sync.sh); the app reads the new names.
    - Docs follow (SYS_DATA_CONNECTOR.MD, AGENTS.md, ROUTER.MD, ERRORS.MD, RUNIT.MD, SYS_*.MD, VM_CORE.MD, skills).
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2026-11-01 wire: session, providers, subscribers; errors with seq and src
    b2 err_cmd_t carries seq and src, err_record_cmd_t and err_record_parse.
    b3 sys_data_provider registry; sys_ble and sys_uart as its drivers, UART
    binary (COBS + CRC16).
    b4 sys_session, the client side: header [frame][dst][src][seq], HELLO with
    your_id, PING, NO_SESSION; its timeout is the dead-man. The router's links
    are gone.
    b5 connectors on the session: SUBSCRIBE / UNSUBSCRIBE / LIST, LOGS bound to
    the BLE LOGS characteristic.
    The app, the Python suites and the docs follow. _wire_draft/ holds the
    specification and PLAN.MD for the steps still open.
2026-11-01 watch: reads the board runs by a period, a change or an event
    sys_watch: ADD / REMOVE / LIST on root key 0x0F (error module 19); a watch's
    read is a router_inject, its entry [owner][id][status][data] is made in the
    answer's buffer and goes to the owner as a STREAM frame
    ([SYS_DATA_CONNECTOR_WATCHES][entry]) or to a connector. ON_CHANGE keeps the
    CRC of the last entry and a max silence; ON_EVENT subscribes its filter
    (sys_event_filter_t in sys_event). A gone owner's watches end.
    The app's backend: contract_watch.json, the watches stream with its seq,
    Watches (add, remove, added again after a reconnect). _wire_draft/sys_watch
    keeps the client and the cached reads (step 4).
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2026-11-01 remote devices: the connector's mirrors, the watch client and cached reads, CREATE_REMOTE and sys_remote; remote_tests.py passes on two boards
    A VM program on the root blinks a pin of the child (PERIODIC 1 s, TOGGLE of a remote GPIO). The device block takes ERR_SESSION_BUSY as later and a missing first copy as no value.
2026-11-01 events: EVENTS_ALL and SYS_EVENT_LOCAL; sys_remote mirrors a board's events and errors as the remote device's
2026-11-01 errors: the board as the source of an error, a policy per board; dummy errors on the devkit pass in remote_tests.py (35/35)
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2026-11-04 save: stream rework in the firmware (sys_data_connector is sys_stream: one direction, one list of targets; watches in session channel 0x80; remote device as an alias with REMOTE key 0x10 and channel 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
    Also saves the work in progress on this branch: session split (call/, hello/), lvgl-playground, the dataflow and display diagrams, wire notes.
2026-11-04 host tests: errors, cmd and router built with gcc and Unity on the PC (runit-esp/test_host: run.py, a FreeRTOS stand-in with tasks as threads); ERR_HDR_LEN from sizeof(void*); ERR_POOL_EMPTY without 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
2026-11-09 sys_display: the DISPLAY device contract (0x0A: GEOMETRY, BACKLIGHT, FLUSH by buffer id, event FLUSH_DONE) with its buffer table (sys_display_buffer_set / _get) and error module; API.html: every rout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
2026-11-09 DISPLAY contract for SPI panels and op flags in the contract tables: DISPLAY is SPI only (no I2C, no mono): formats RGB565_SWAPPED / RGB888, the new op ORIENTATION, the glass in display_cfg_t (SPI mo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
2026-11-09 DISPLAY ORIENTATION local, DEVICE event RESET: ORIENTATION is SYS_DEVICE_OP_LOCAL (out of contract_display.json; only the screen adapter's ROTATION turns the panel, refused while a FLUSH is in flight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
2026-11-09 DISPLAY interface review: the display's errors name their device (MODULE_ID_KINDS), ERR_DISPLAY_TRANSFER's code is an esp_err_t, ERR_DISPLAY_FLUSH_TIMEOUT's field is timeout_ms (unit ms); OPS leaves 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
2026-11-09 LVGL adapter, TOUCH contract and the display on a simulated SPI panel: sys_lvgl (the LVGL adapter on a DISPLAY and a TOUCH device, key 0x15) and sys_touch; DISPLAY contract: panel enum (sys_display_p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
